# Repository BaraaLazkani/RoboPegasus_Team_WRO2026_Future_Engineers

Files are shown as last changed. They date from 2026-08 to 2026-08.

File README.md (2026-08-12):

RoboPegasus — WRO Future Engineers 2026
====

<p align="center">
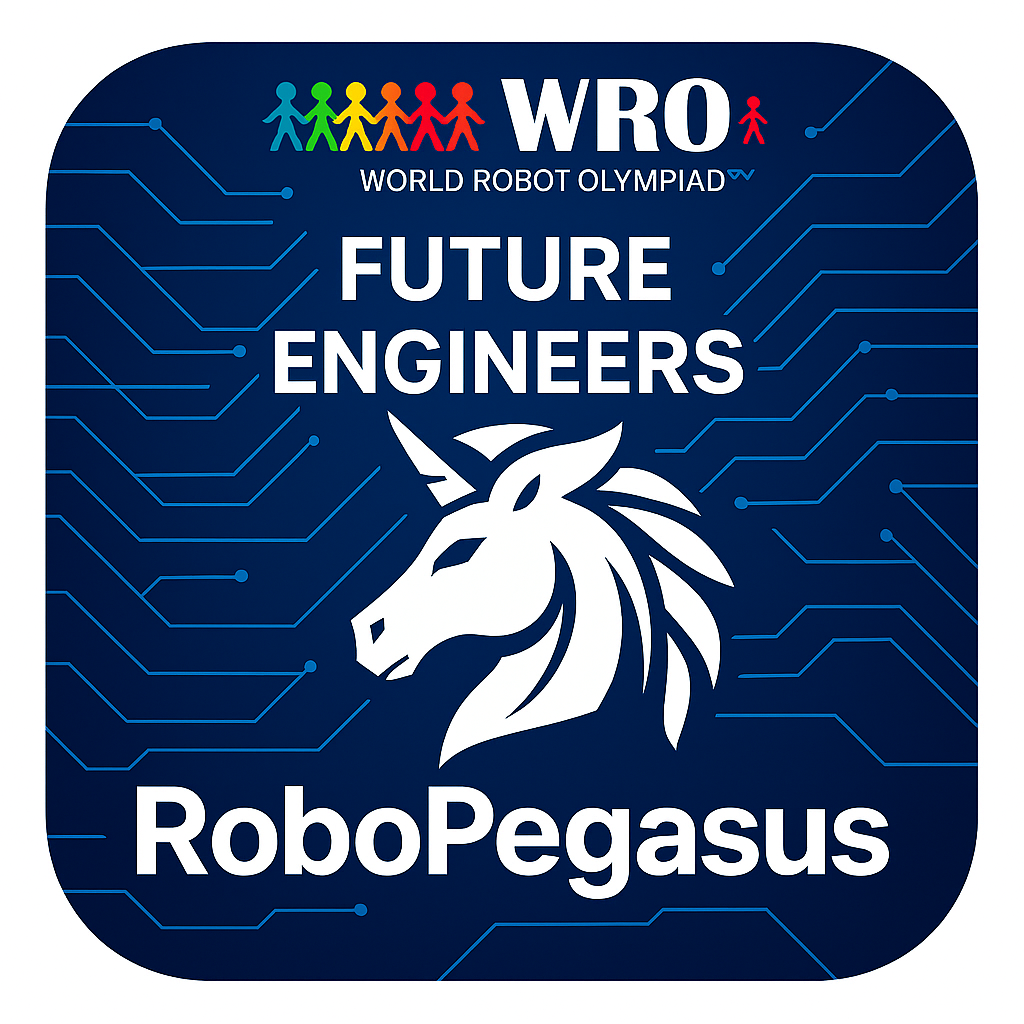
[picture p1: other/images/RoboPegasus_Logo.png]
RoboPegasus Logo
  
</p>

This repository holds the engineering documentation for RoboPegasus's
autonomous vehicle, built for the 2026 season of the WRO Future Engineers
competition.

### Table of contents

1. [Engineer's Documentation on GitHub](#engineers-documentation-on-github)
2. [Mobility and Mechanical Design](#mobility-and-mechanical-design)
3. [Power and Sensor Architecture](#power-and-sensor-architecture)
4. [Software Architecture and Obstacle Strategy](#software-architecture-and-obstacle-strategy)
5. [Systems Thinking and Engineering Decisions](#systems-thinking-and-engineering-decisions)
6. [Team and Age Groups Definitions](#team-and-age-groups-definitions)
7. [Responsibilities and Team's Own Work](#responsibilities-and-teams-own-work)
8. [Vehicle Material & Regulations Compliance](#vehicle-material--regulations-compliance)

## Engineer's Documentation on GitHub

### Repository

Our 2026 repository is public at
[github.com/BaraaLazkani/RoboPegasus_Team_WRO2026_Future_Engineers](https://github.com/BaraaLazkani/RoboPegasus_Team_WRO2026_Future_Engineers).
It will remain public for at least 12 months following the international
competition.

Access note: viewers in some restricted regions may need a VPN to reach
the repository.

### Repository structure

Our repository uses the following top-level folder structure:

```
.github/     # GitHub issue templates
t-photos/    # Team photos
v-photos/    # Vehicle photos (all sides, top, bottom)
video/       # Video demonstrations and links
schemes/     # Electrical schematics and diagrams
src/         # Source code for all components
models/      # 3D printed and laser cut parts
other/       # Additional resources (images, files, GIFs)
README.md    # This documentation
LICENSE      # Project license
CONTRIBUTING.md      # How to contribute
CODE_OF_CONDUCT.md   # Community code of conduct
SECURITY.md          # Security policy
```

`src/` contains every component we programmed for the competition.
`models/` contains the 3D-printed part files (`models/STL Files/`) and
laser-cut part files (`models/Cut/`) we used to fabricate the vehicle's
elements.

### Videos

Open Challenge: [youtube.com/watch?v=jy_cDW6b-VM](https://www.youtube.com/watch?v=jy_cDW6b-VM).

Obstacle Challenge: [youtube.com/watch?v=_Zi2wvzxyvg](https://www.youtube.com/watch?v=_Zi2wvzxyvg).

### Build, compile, and upload

The vehicle's control software splits into two parts, one for each of the
processors described in Power and Sensor Architecture:

- **Arduino Mega code** (sensor acquisition, motor control, real-time
  navigation): open the sketch in the Arduino IDE, select the Arduino
  Mega 2560 board and the correct serial port, then upload over USB.
- **Raspberry Pi code** (computer vision, pillar detection): run the
  Python script directly on the Pi with Python 3; no separate build step
  is required.

Once both boards are running, the Arduino and the Pi talk to each other
over a USB serial connection (see Power and Sensor Architecture:
Processing); source files for both live in `src/`.

### Vehicle photos

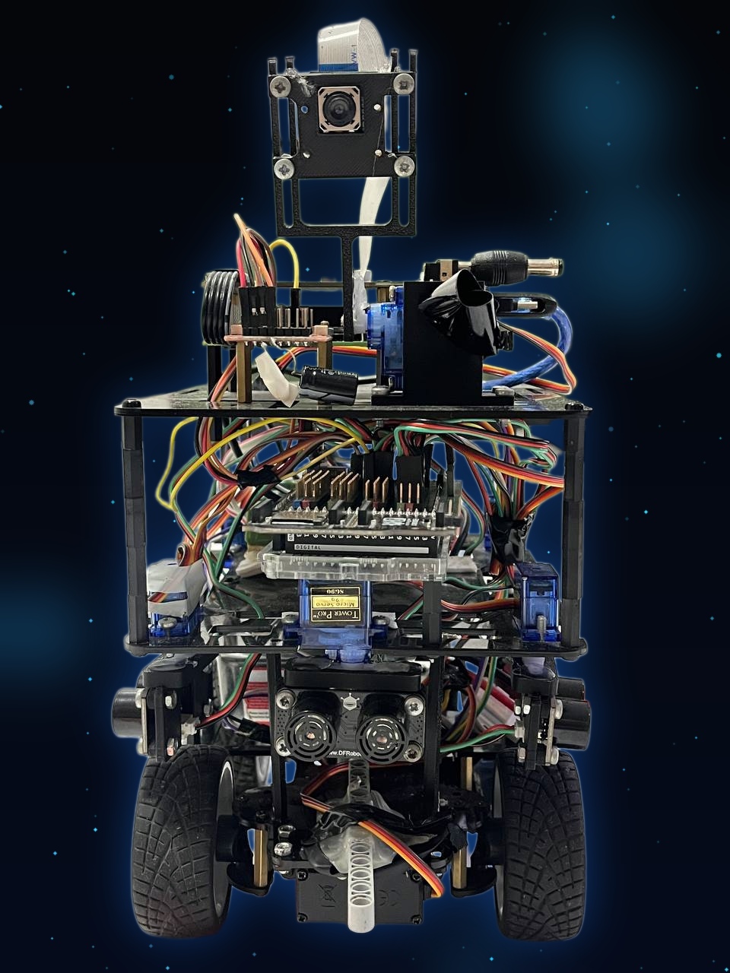
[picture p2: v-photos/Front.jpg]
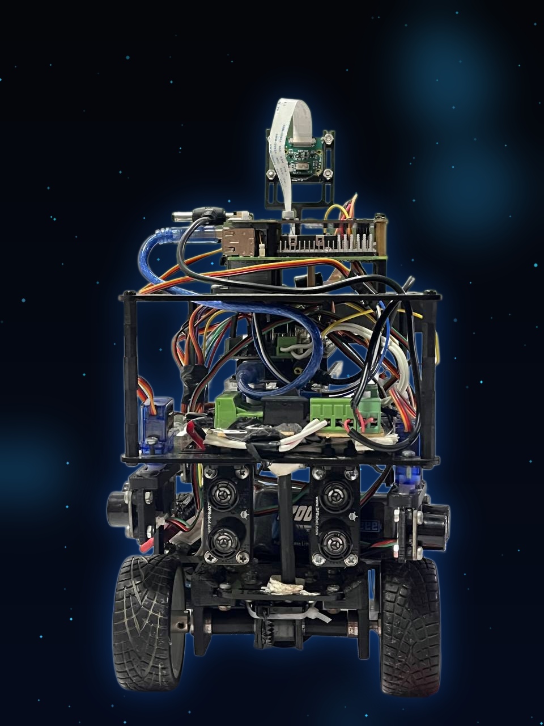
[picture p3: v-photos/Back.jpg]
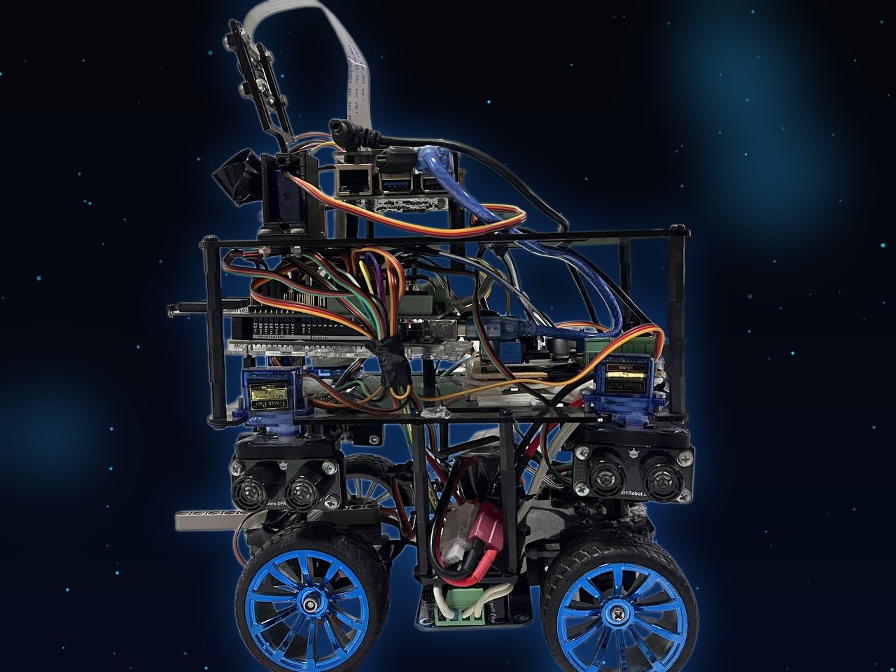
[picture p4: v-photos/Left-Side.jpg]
|  |  |  |
|:---:|:---:|:---:|
| _Front_ | _Back_ | _Left_ |
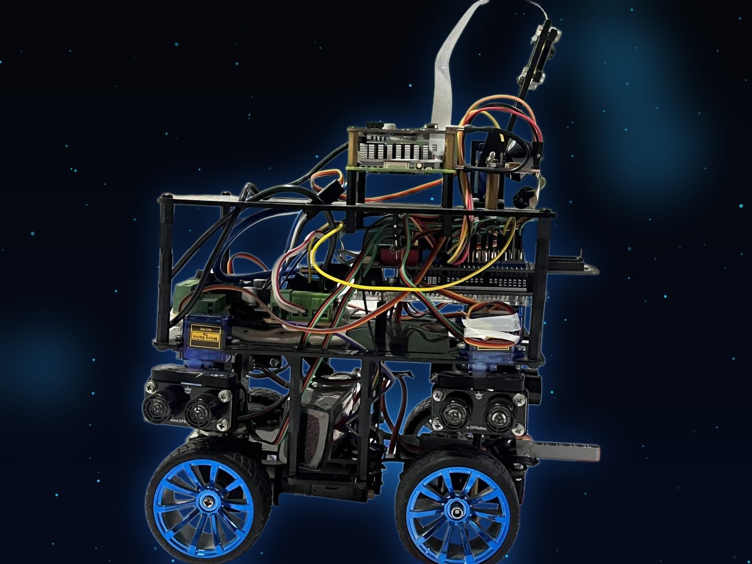
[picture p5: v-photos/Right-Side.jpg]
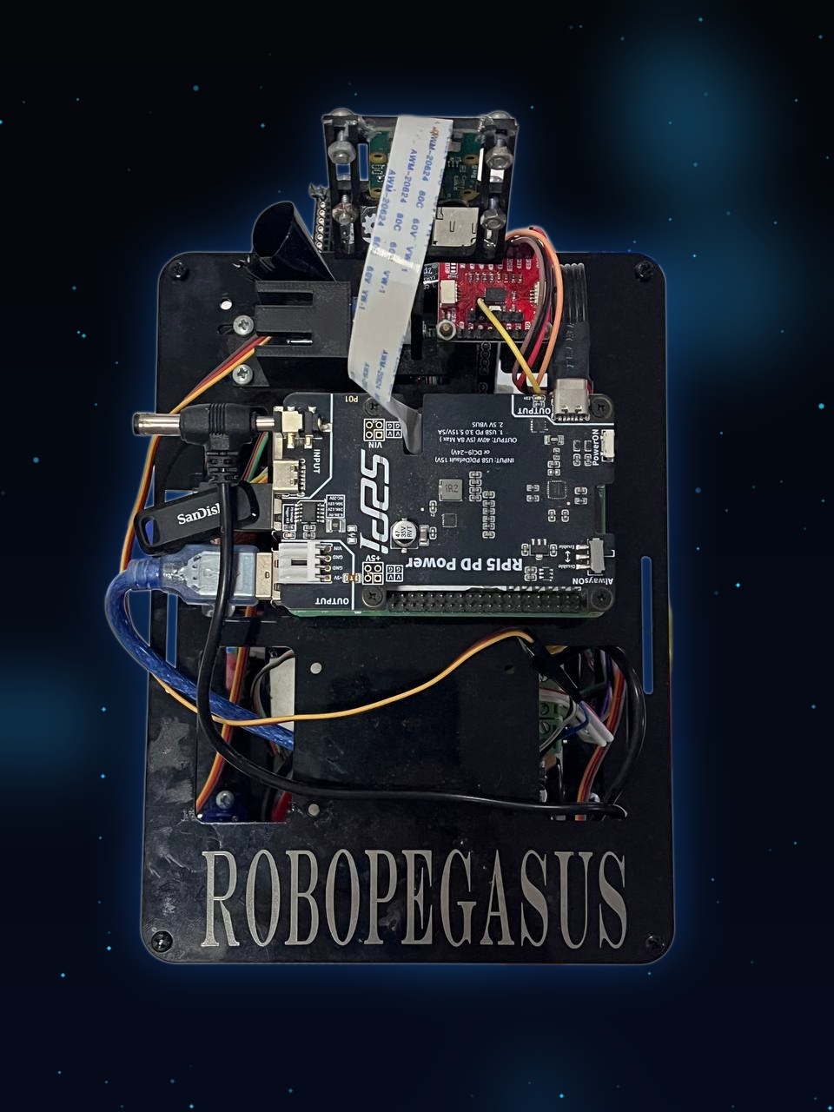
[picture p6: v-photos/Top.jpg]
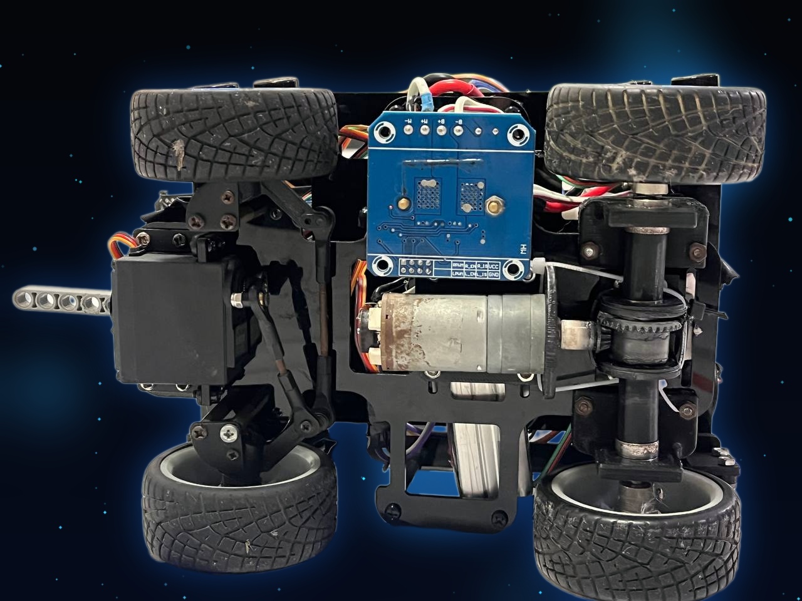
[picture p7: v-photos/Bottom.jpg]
|  |  |  |
| _Right_ | _Top_ | _Bottom_ |

Full-resolution versions of these photos live in `v-photos/`.

### Commit history

Commits go up continuously as work wraps, with every team member
contributing roughly evenly over time.

### Hard copy

This repository also includes a hard copy of this documentation, the
Engineering Journal (`Engineering-Journal.pdf`).

## Mobility and Mechanical Design

This section describes our chassis design choices, the steering and
drive mechanism, our torque/speed reasoning, and how we approached
mechanical stability and rigidity.

### Chassis

The chassis uses a hybrid material approach: 3mm plexiglass panels for
primary structural elements, combined with PLA 3D-printed components for
complex mechanical interfaces. Overall vehicle dimensions are 24cm length
x 15cm width x 29cm height, with a total system weight of 1.45kg.

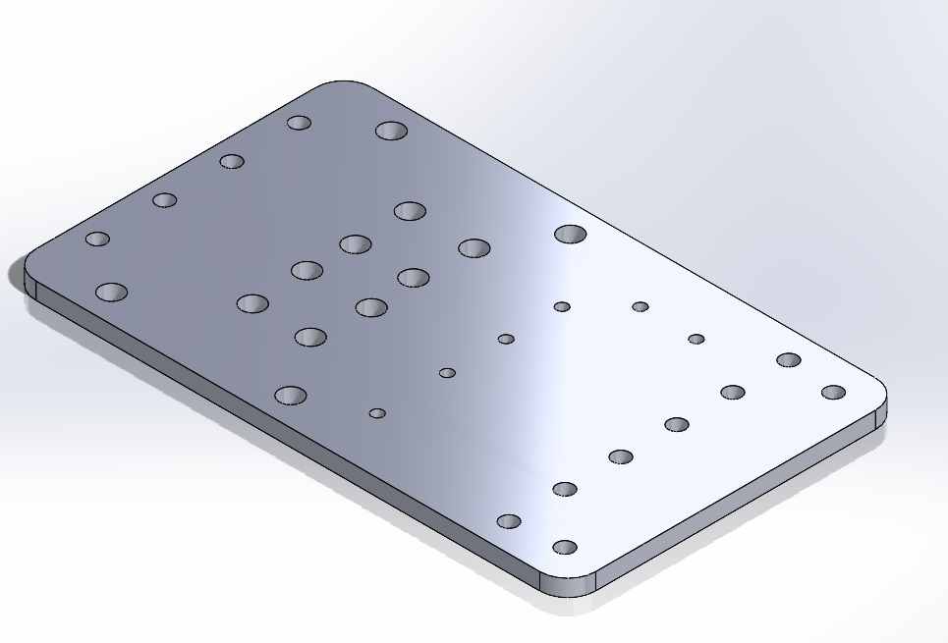
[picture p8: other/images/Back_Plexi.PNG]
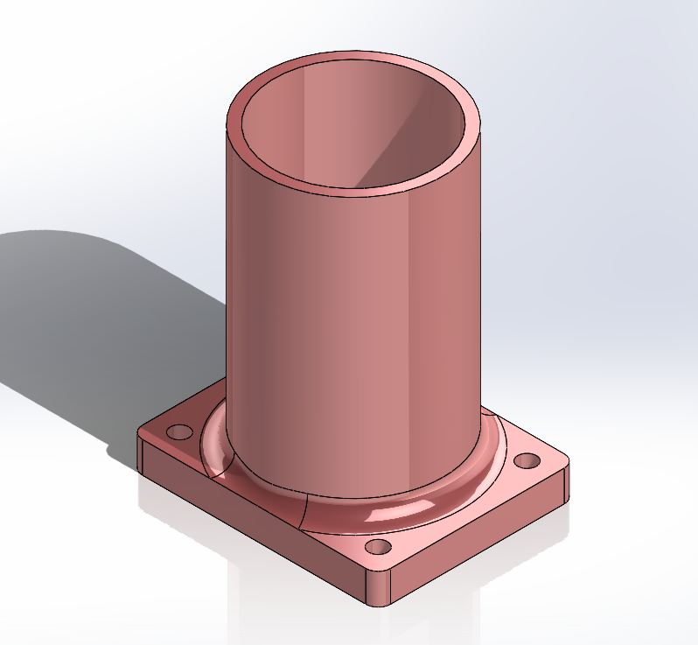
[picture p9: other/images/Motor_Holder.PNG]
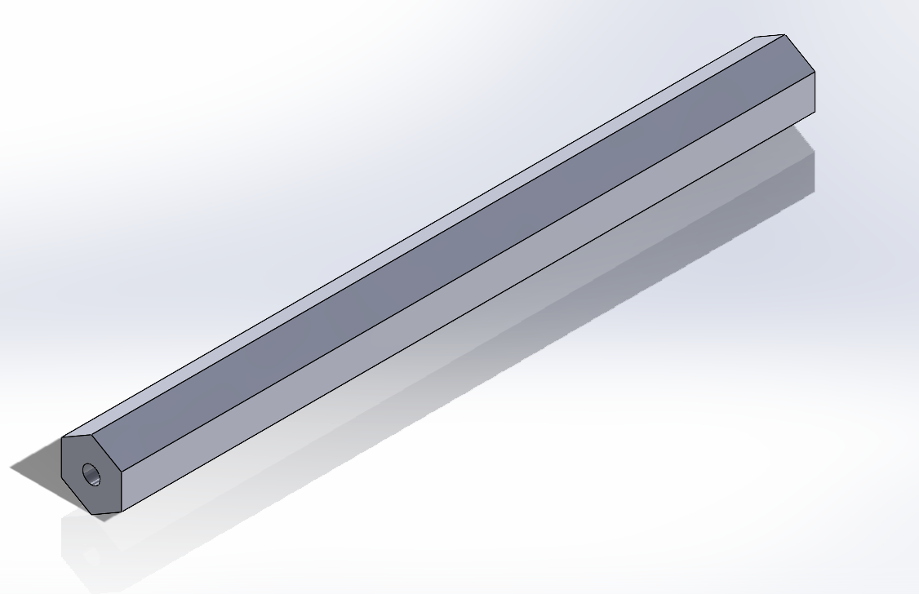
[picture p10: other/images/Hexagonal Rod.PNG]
|  |  |  |
|:---:|:---:|:---:|
| _Rear plexi panel with differential mechanism_ | _Motor holder_ | _Hexagonal drive rod_ |

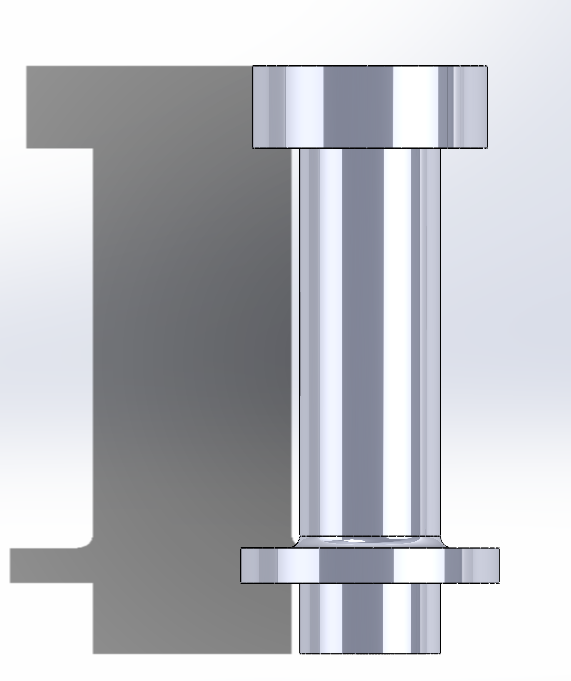
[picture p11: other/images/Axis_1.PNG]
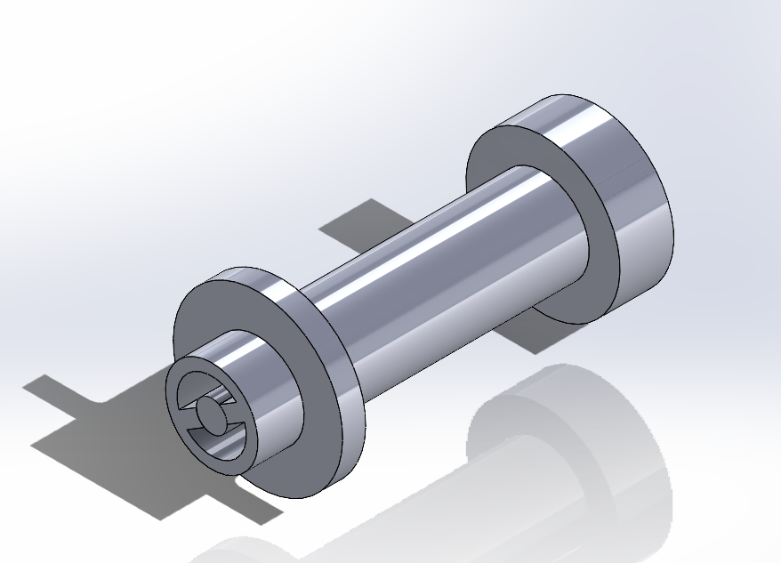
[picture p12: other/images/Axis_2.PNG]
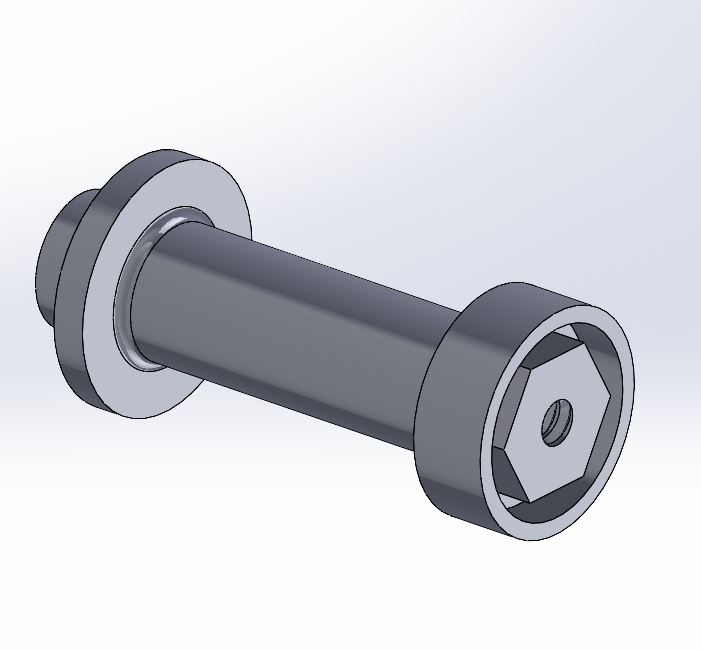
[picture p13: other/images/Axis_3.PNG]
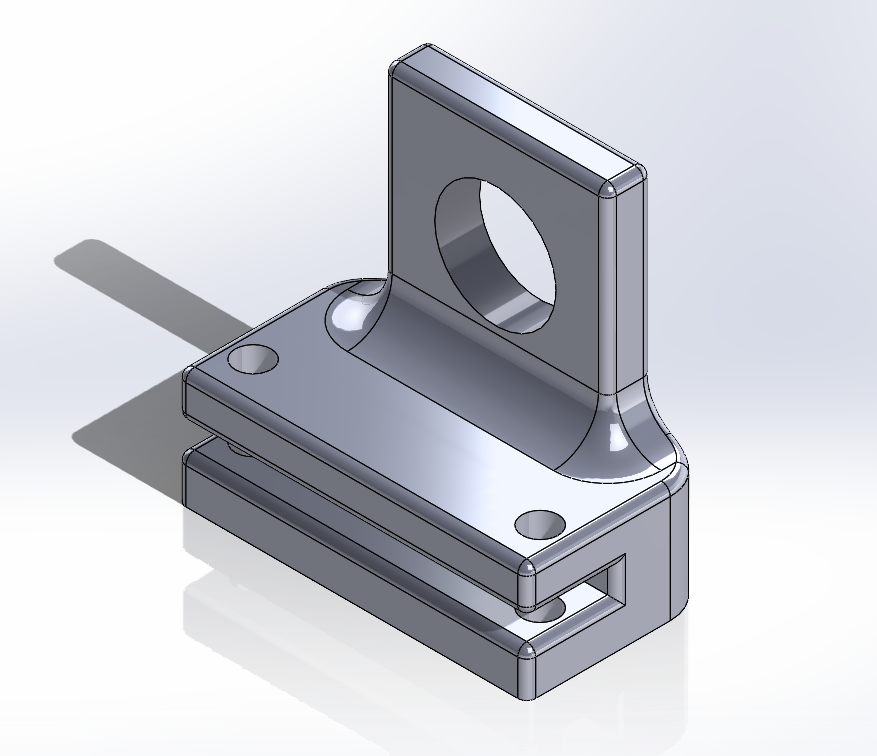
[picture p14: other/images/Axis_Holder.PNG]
|  |  |  |  |
|:---:|:---:|:---:|:---:|
| _Axis assembly, view 1_ | _Axis assembly, view 2_ | _Axis assembly, view 3_ | _Axis holder_ |

### Drivetrain

The primary drivetrain uses a JGA25-370 DC motor operating at 245 RPM,
selected for its balance of torque, power efficiency, and cost. At 12V, the
motor delivers 350 RPM no-load speed at 0.1A, reaching maximum efficiency
at 245 RPM with 1.4 kg-cm torque and 2.4W power consumption; its stall
specifications are 5.2 kg-cm torque at 2.2A. An integrated 3:1 gearbox
raises output torque to 4.2 kg-cm while reducing output speed to
approximately 82 RPM. With a 32mm wheel radius, this yields a tractive
force of approximately 12.85 N and a linear velocity of approximately
0.27 m/s at maximum efficiency, comfortably powering the 1,475g vehicle
(at an estimated 0.02 rolling-resistance coefficient, the calculated power
required for constant velocity is roughly 0.09W with the motor's ~90%
efficiency factored in) -- substantial reserve capacity above and beyond
the minimum required for propulsion, which we rely on for acceleration and
dynamic maneuvering.

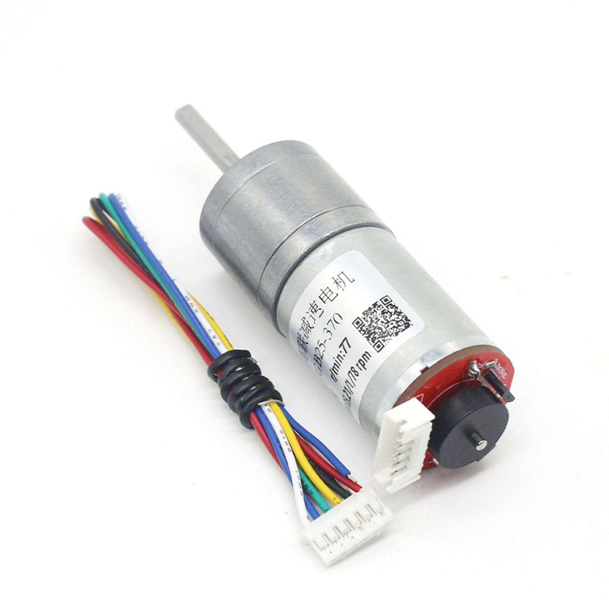
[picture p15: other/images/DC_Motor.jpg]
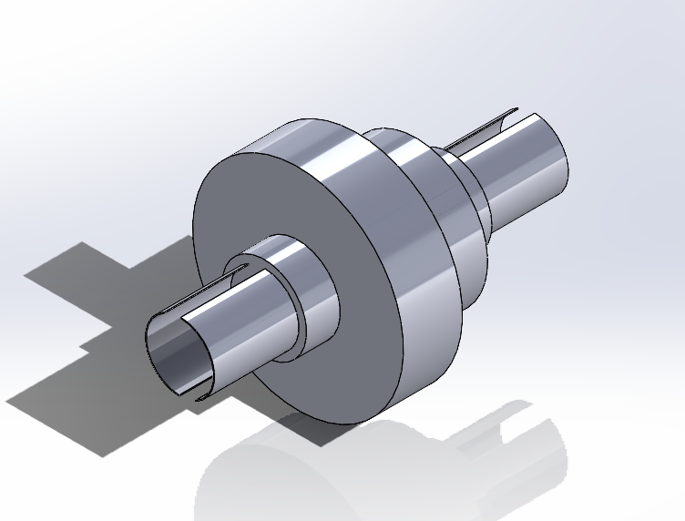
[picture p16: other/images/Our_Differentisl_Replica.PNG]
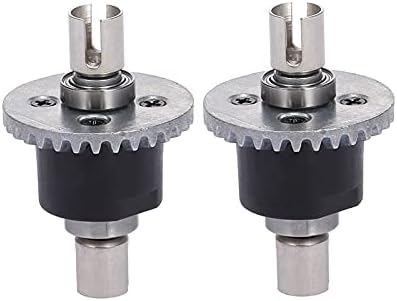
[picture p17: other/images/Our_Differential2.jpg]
|  |  |  |
|:---:|:---:|:---:|
| _JGA25-370 DC motor_ | _Custom differential replica_ | _Custom differential, view 2_ |
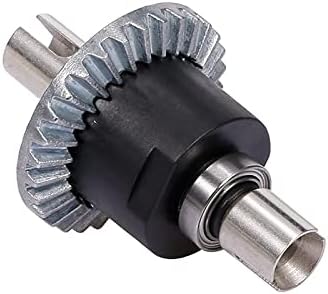
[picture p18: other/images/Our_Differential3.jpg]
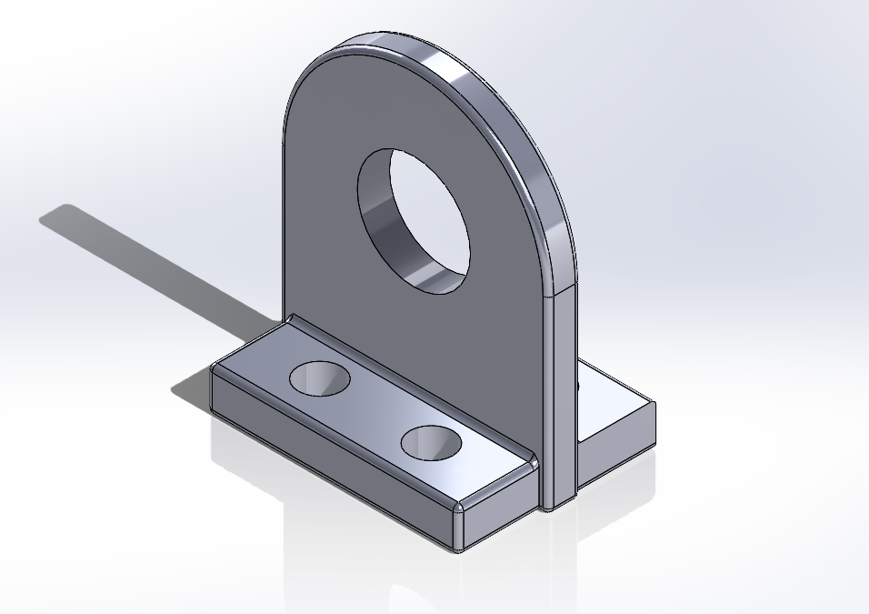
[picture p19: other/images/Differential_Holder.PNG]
|  |  | |
| _Custom differential, view 3_ | _Differential holder_ | |

Our rear axle uses a custom differential mechanism (not an electronic,
one-motor-per-side setup) -- for reference, the two broad differential
types this design draws on:

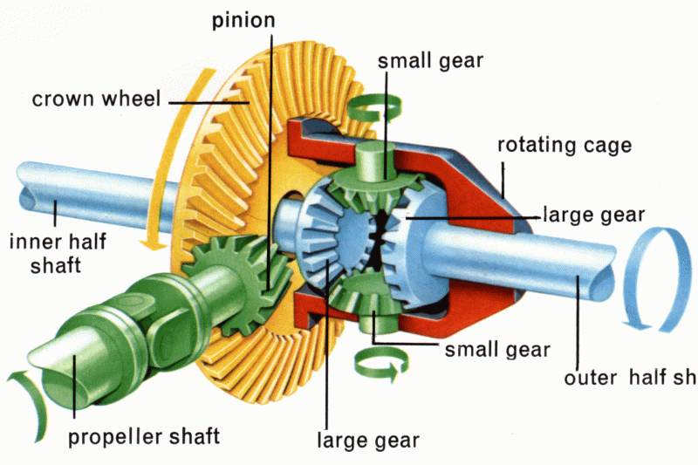
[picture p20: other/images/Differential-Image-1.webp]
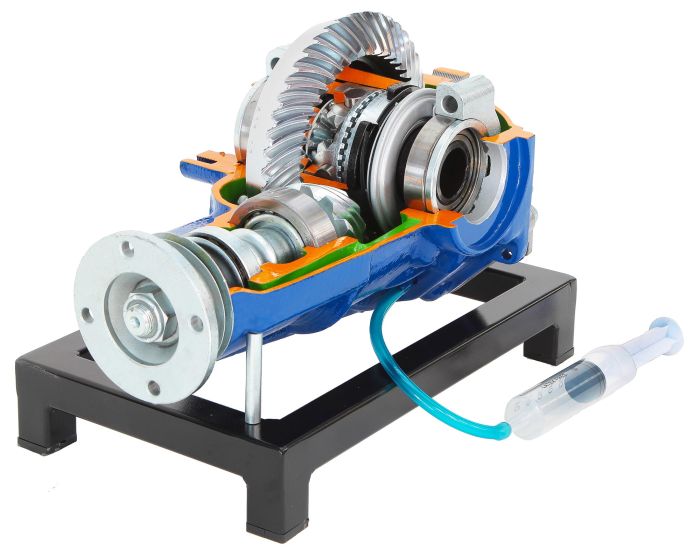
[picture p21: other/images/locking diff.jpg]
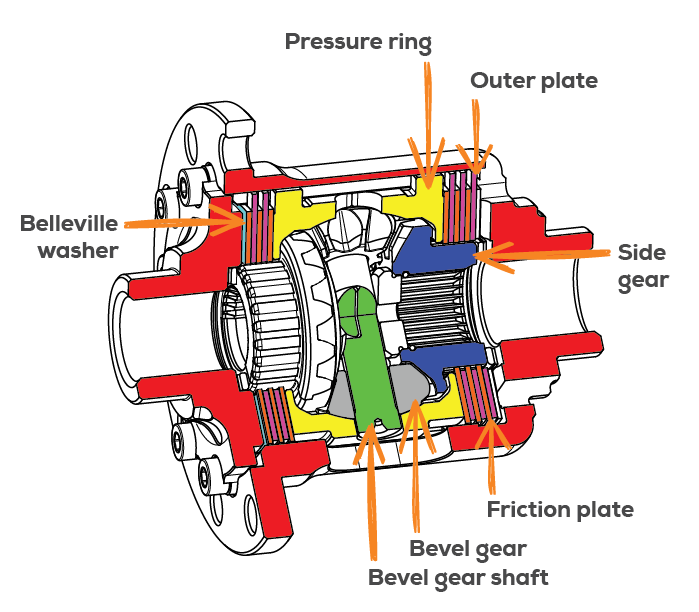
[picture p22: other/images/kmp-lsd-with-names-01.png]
|  |  |  |
|:---:|:---:|:---:|
| _Open differential_ | _Locking differential_ | _Limited-slip differential_ |

### Steering

The vehicle uses Ackermann steering, driven by an MG996R high-torque servo
(9.4 kg-cm stall torque at 4.8V, 11 kg-cm at 6V; 0.17s/60 degrees and
0.14s/60 degrees at those respective voltages), which receives direct PWM
signals from the Arduino Mega with no additional driver circuitry, keeping
steering-response latency low. The Ackermann steering geometry itself was
adapted from an existing 4WD Ackermann chassis kit -- the only major
component adapted from an outside design rather than built from scratch --
because the original kit's chassis platform (approximately 24cm) was far
larger than our target robot size (16-18cm). We identified the essential
mounting holes, pivot points, and structural elements from the forward
section of the original mounting plate, then used CAD modeling to
reproduce that section's exact hole spacing and angular relationships at
our compact scale, preserving the steering geometry while eliminating the
unusable length of the original plate.

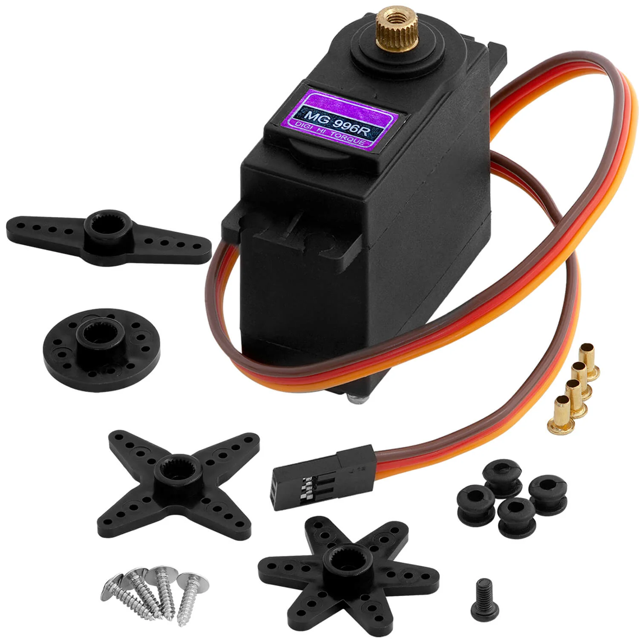
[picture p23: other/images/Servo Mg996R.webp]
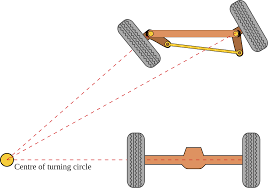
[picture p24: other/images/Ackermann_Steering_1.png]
|  |  |
|:---:|:---:|
| _MG996R steering servo_ | _Ackermann steering geometry_ |
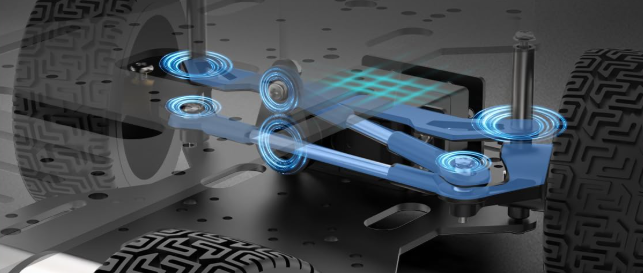
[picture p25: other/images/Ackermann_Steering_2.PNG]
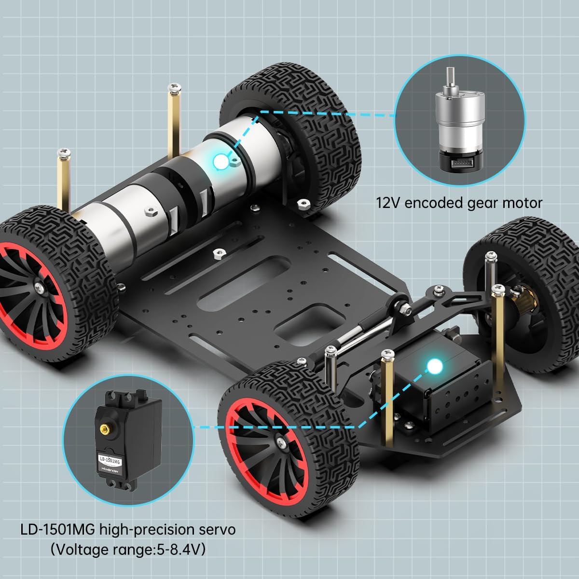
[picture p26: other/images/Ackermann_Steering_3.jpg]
|  |  |
| _Ackermann steering, how it works_ | _Original vs. custom design comparison_ |

### Testing and iteration

Before locking in the design, we validated our gear reduction and
drivetrain setup against our target performance figures.

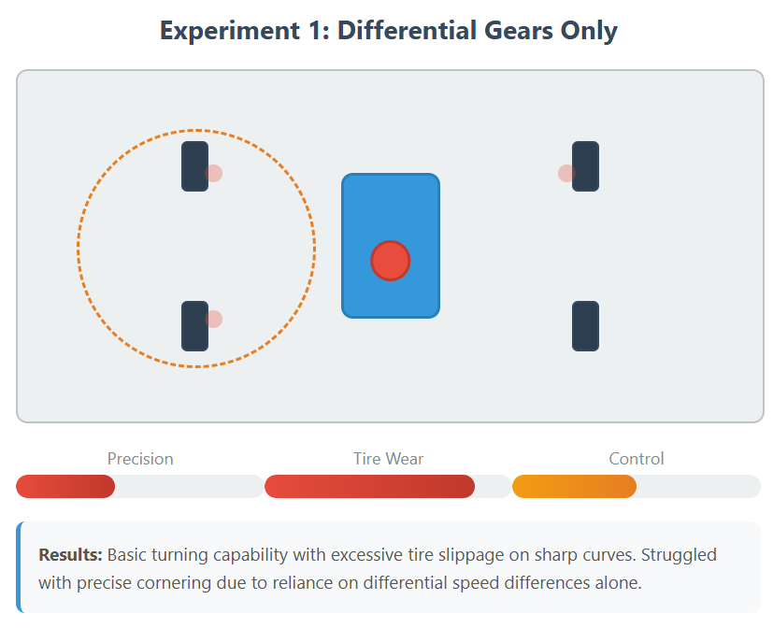
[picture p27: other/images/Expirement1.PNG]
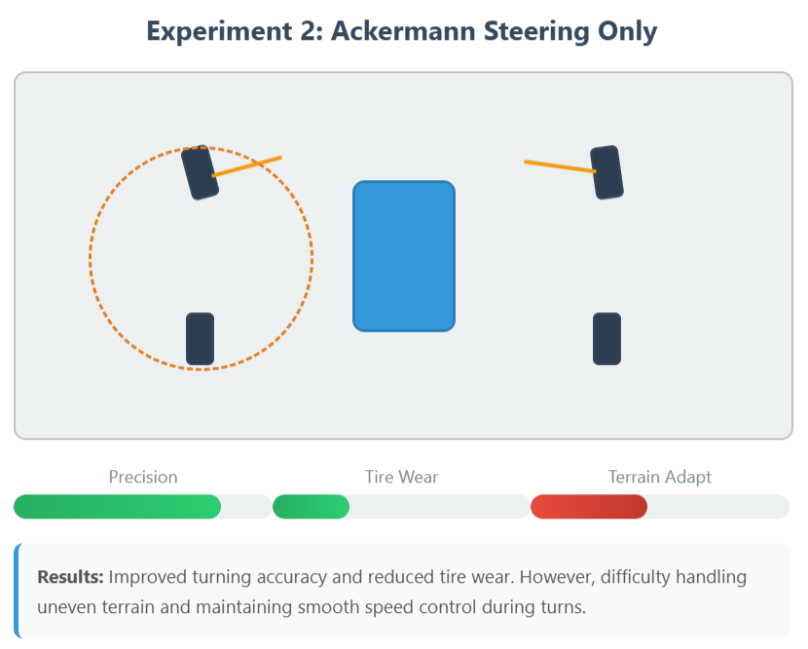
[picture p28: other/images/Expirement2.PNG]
|  |  |
|:---:|:---:|
| _Mechanical test 1_ | _Mechanical test 2_ |
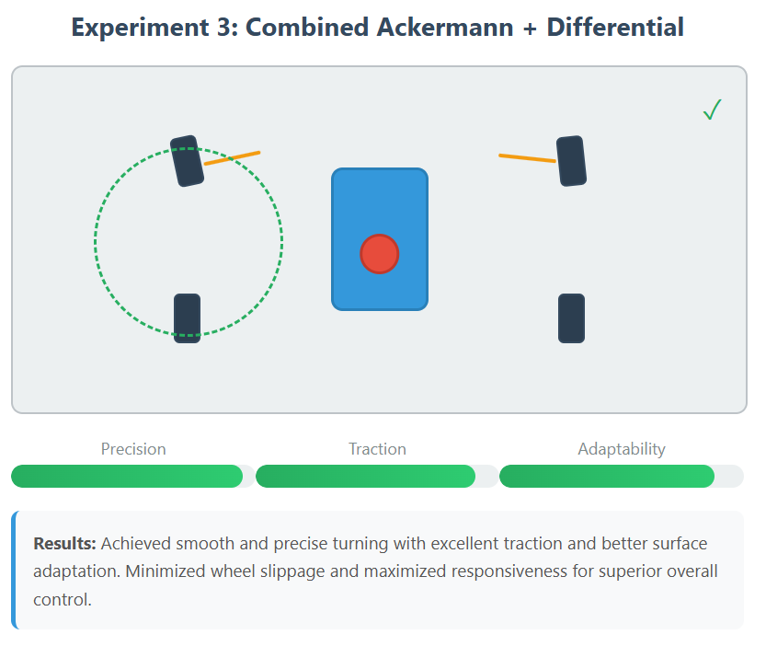
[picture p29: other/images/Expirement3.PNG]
|  |  |
| _Mechanical test 3_ | _Test legend_ |

The photos above show the gear-ratio testing described earlier.

Aside from the gear-ratio tuning covered above, we haven't yet written up
any further 2026-specific mechanical tests or design changes; that will
be added as the testing happens.

## Power and Sensor Architecture

This section walks through our power system architecture, the reasoning
behind our current draw and distribution, how sensors were chosen and
placed, our calibration approach, and the wiring diagrams.

### Power source and distribution

The robot is powered by a Zeee Li-Poly battery: 11.1V (3S configuration),
2200mAh capacity, 50C continuous discharge rate, up to 110A continuous
maximum current output, approximately 185g, with an XT60 connector. Power
is distributed using a custom Power Management System (PMS) built on a
star topology -- each component receives power directly from a central
distribution point rather than a daisy chain, which avoids voltage drops
and current-induced interference between subsystems, isolates each
component's current draw from the others, and simplifies fault isolation
and cable management. The battery's 50C/110A capacity comfortably covers
simultaneous peak demand from the drivetrain, processors, and sensor array
without voltage sag. At a typical estimated operating power draw, the
battery supports roughly 50 minutes of runtime, with a safety-factor
budget (80% battery usage) of roughly 41 minutes -- comfortably covering
multiple competition runs per charge.

The PMS includes a dedicated DC-DC step-down converter, which regulates
and stabilizes the battery's raw voltage down to what the Raspberry Pi 5
(SBC) and Arduino Mega (SBM) require.

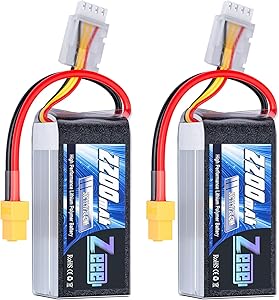
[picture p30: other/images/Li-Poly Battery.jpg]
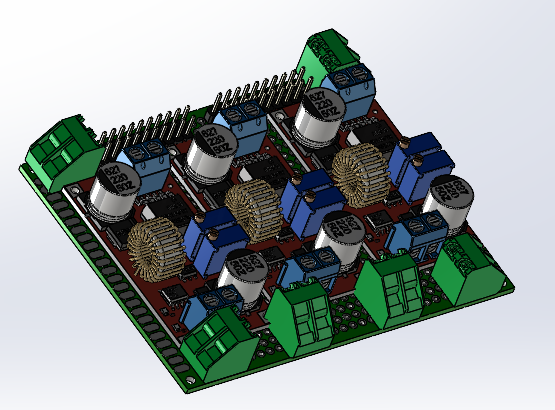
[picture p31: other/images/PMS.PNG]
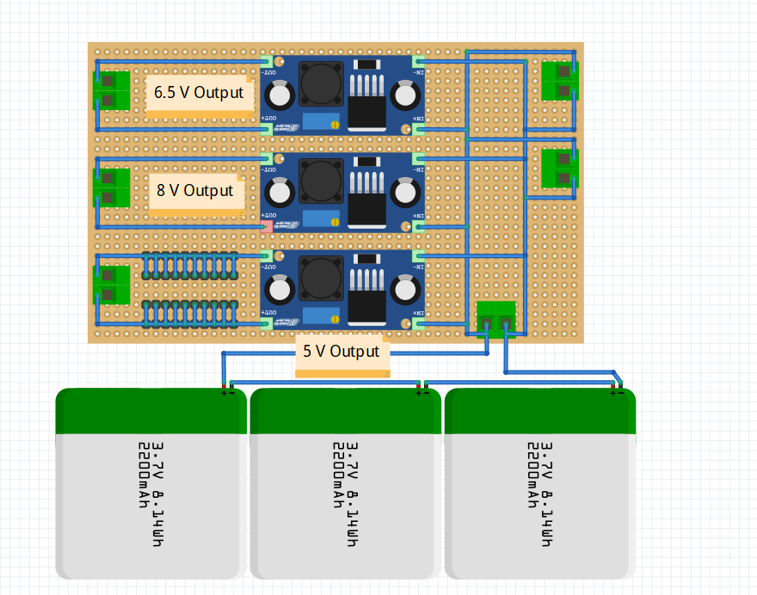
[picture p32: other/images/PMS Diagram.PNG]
|  |  |  |
|:---:|:---:|:---:|
| _Zeee Li-Poly battery, 11.1V 2200mAh_ | _Custom Power Management System_ | _PMS schematic diagram_ |

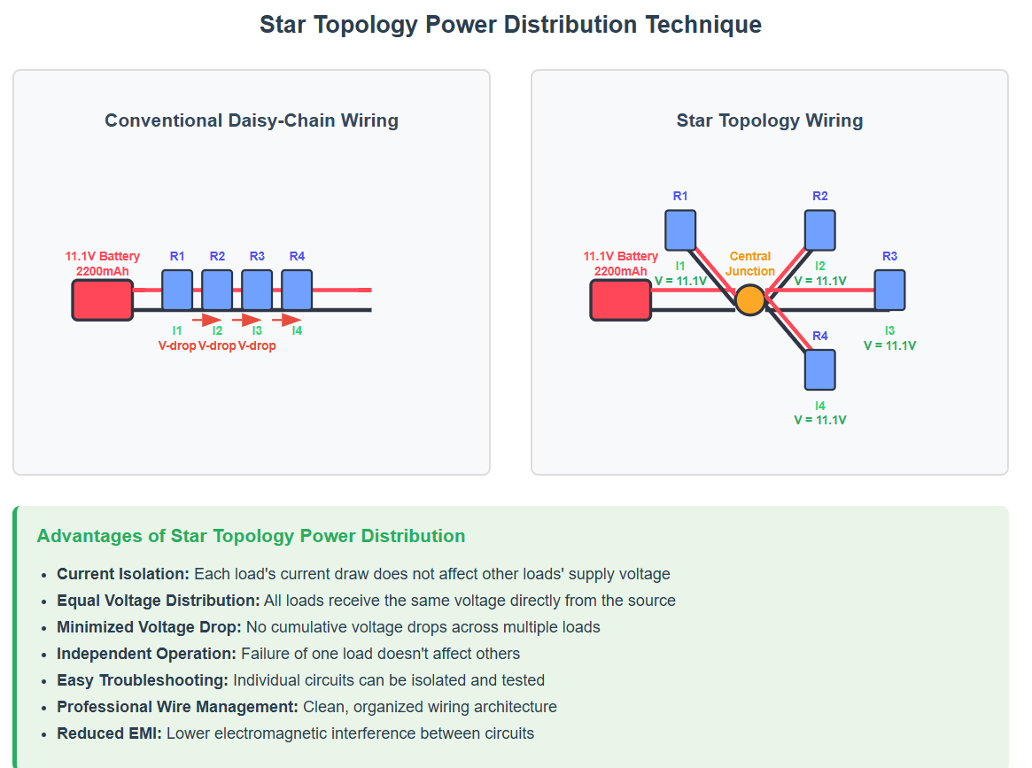
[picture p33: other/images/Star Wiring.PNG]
|  |
|:---:|
| _Star-topology power distribution_ |

### Processing

An Arduino Mega 2560 serves as the primary sensor interface and real-time
control processor -- handling sensor data acquisition, motor control, and
real-time navigation decisions -- chosen for its cost-effectiveness, 54
digital pins and 16 analog inputs (enough I/O for our full sensor array),
and proven reliability in robotics applications. A Raspberry Pi 5 (8GB RAM,
with active cooling) handles computer vision processing separately; active
cooling specifically guards against thermal throttling in high ambient
temperatures such as summer competition conditions. The two processors
communicate over a USB serial connection, exchanging computer vision
results and navigation commands.

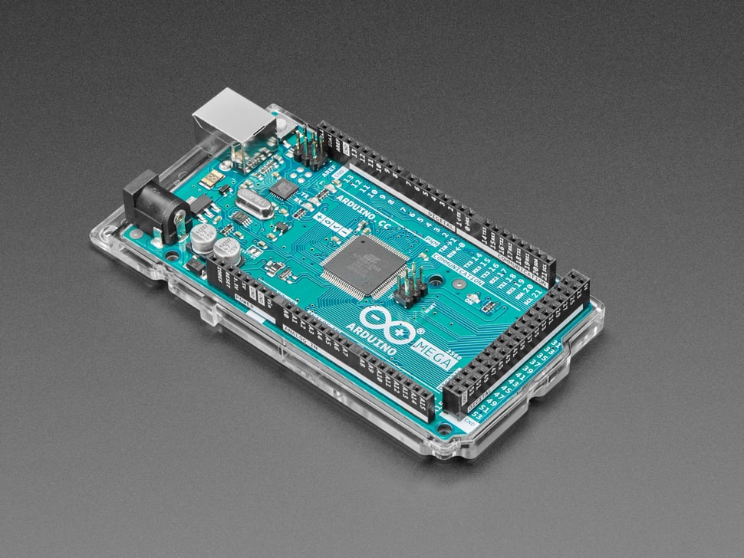
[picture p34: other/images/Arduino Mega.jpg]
|  |  |  |
|:---:|:---:|:---:|
| _Arduino Mega 2560_ | _Raspberry Pi 5 with active cooling_ | _BTS7960 motor driver_ |

### Sensor array

The sensor array is made up of 7 ultrasonic sensors, an IMU, and a camera:

- **Ultrasonic sensors:** 7x DFRobot URM09 (previously HC-SR04). Mounted
  below the 9cm height threshold for reliable wall detection.
- **Dynamic positioning:** 5 servos total (previously 3) -- both
  ultrasonic sensors on the left side now have servos, both on the right
  side now have servos, and the front ultrasonic sensor now also has a
  servo. Dynamic positioning keeps these sensors oriented perpendicular to
  walls regardless of vehicle attitude, which meaningfully improves
  measurement accuracy over a fixed angle.
- **IMU:** SparkFun BNO086 (previously MPU6050), providing orientation and
  acceleration data for dead reckoning and complementing the ultrasonic
  array for navigation.
- **Camera:** Arducam 64MP Hawk-Eye module, for computer vision tasks
  including pillar detection/classification and path planning.

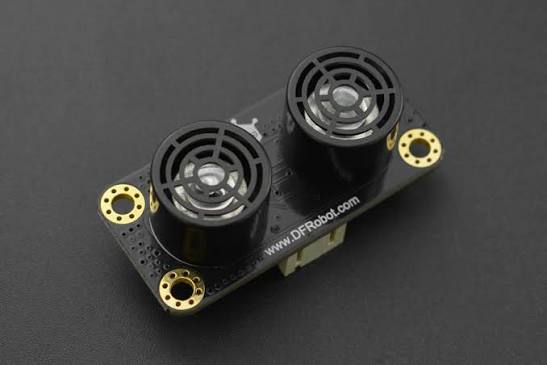
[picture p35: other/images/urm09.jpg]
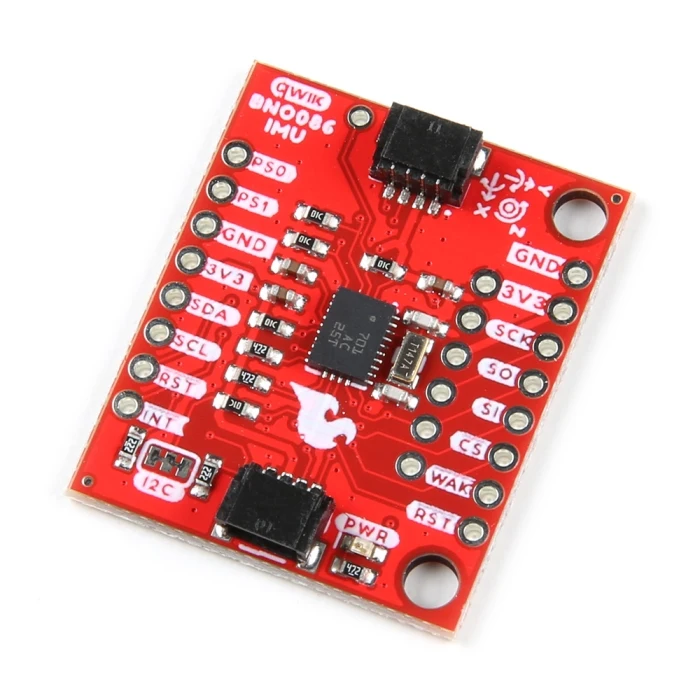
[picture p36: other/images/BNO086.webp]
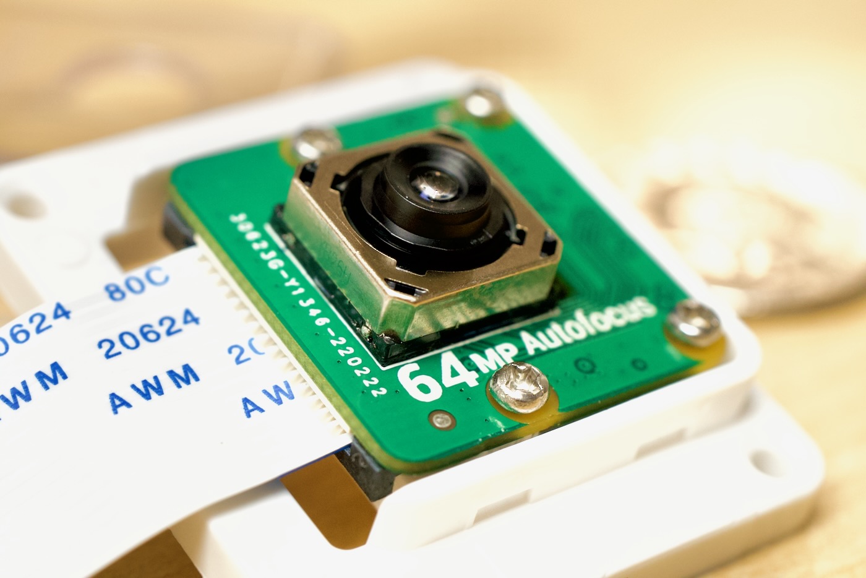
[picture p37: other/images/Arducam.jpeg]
|  |  |  |
|:---:|:---:|:---:|
| _DFRobot URM09 ultrasonic sensor_ | _SparkFun BNO086 IMU_ | _Arducam 64MP Hawk-Eye camera_ |

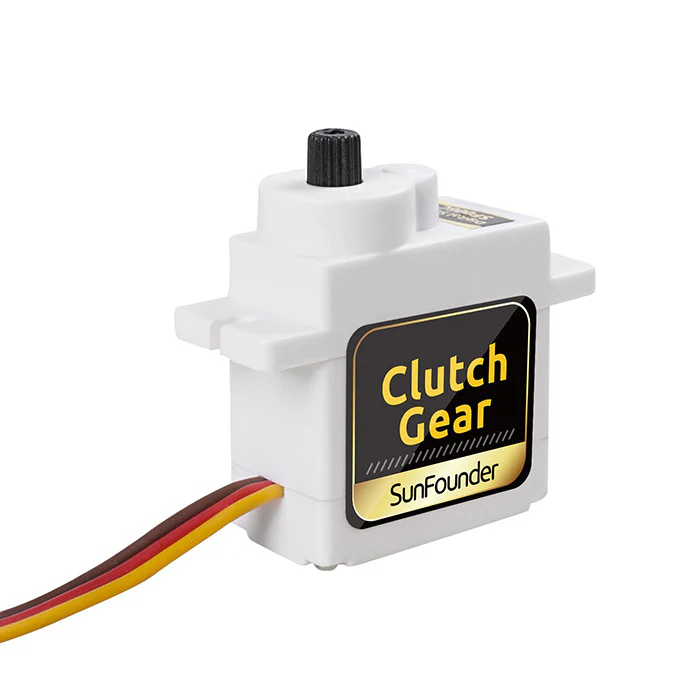
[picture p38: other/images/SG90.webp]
|  |
|:---:|
| _SG90 servo, dynamic sensor positioning_ |

### Sensor placement: field geometry and failure-point reasoning

We chose sensor placement based on how the robot's own geometry shifts
relative to the walls during a maneuver, not on a generic "more sensors
is better" logic:

- **Two rear ultrasonics** let the parking routine know when the robot is
  fully inside the parking lot -- a distinct requirement from the side
  sensors' wall-following role.
- **Two ultrasonics per side (front-axle and rear-axle),** rather than
  one, because which end of the robot is actually closest to the wall
  depends on the maneuver: driving forward while turning right brings the
  *front* of the robot closest to the wall, while driving backward while
  turning right brings the *back* of the robot closest to the wall. A
  single side sensor would be reading the wrong distance during roughly
  half of these maneuvers; having one sensor near each axle means the
  relevant distance is always available on both sides regardless of
  direction of travel or turn.
- **The same front/rear-axle side-sensor pair also compensates for IMU
  drift:** since the two sensors' physical separation is known, the robot
  can geometrically compute how many degrees it has actually drifted from
  the two distance readings, and use that to correct the MPU/IMU heading
  reference over time -- a concrete failure-point mitigation for sensor
  drift, not just a navigation feature.
- **The front ultrasonic** exists specifically to detect obstacles
  directly ahead of the robot, a role none of the side/rear sensors can
  fill.
- **Servos on the ultrasonics** exist because ultrasonic ranging accuracy
  degrades sharply once the reflecting surface isn't perpendicular to the
  sensor -- dynamic positioning keeps each sensor perpendicular to the
  wall regardless of the robot's current attitude, which is the whole
  reason the sensor count and servo count both grew for 2026 (see above).

### Bill of materials

A consolidated list of the vehicle's major components, pulled together
from the descriptions above and in Mobility and Mechanical Design:

| Component | Part | Qty | Price (USD) |
|---|---|---|---|
| Chassis | 3mm plexiglass panels + PLA 3D-printed parts | -- | -- |
| Drive motor | JGA25-370 DC motor, 3:1 gearbox | 1 | $20 |
| Steering servo | MG996R high-torque servo | 1 | $8 |
| Sensor-positioning servos | SG90 | 5 | $5 ($1 each) |
| Motor driver | BTS7960 | 1 | $4 |
| Primary controller (SBM) | Arduino Mega 2560 | 1 | $50 |
| Vision processor (SBC) | Raspberry Pi 5, 8GB RAM, active cooling | 1 | $120 |
| Ultrasonic sensors | DFRobot URM09 | 7 | $70 ($10 each) |
| IMU | SparkFun BNO086 | 1 | $34 |
| Camera | Arducam 64MP Hawk-Eye | 1 | $80 |
| Battery | Zeee Li-Poly, 11.1V (3S), 2200mAh, 50C, XT60 | 2 | $80 |
| Power distribution | Custom PMS, star topology, DC-DC step-down converter | 1 | $20 |
| **Total** | | | **$491** (excludes chassis material cost) |

### Wiring diagram

The wiring diagram
(`schemes/Full Schematic Circuit Diagram of the Robot/Full Circuit Diagram
of the Robot.PNG`) was produced in Fritzing, which does not have exact
component symbols for the URM09 ultrasonic or BNO086 IMU, so those two
components are represented with generic/illustrative symbols rather than
exact part renders -- the diagram is accurate for overall wiring topology,
not a literal part-for-part illustration of the newest sensors.

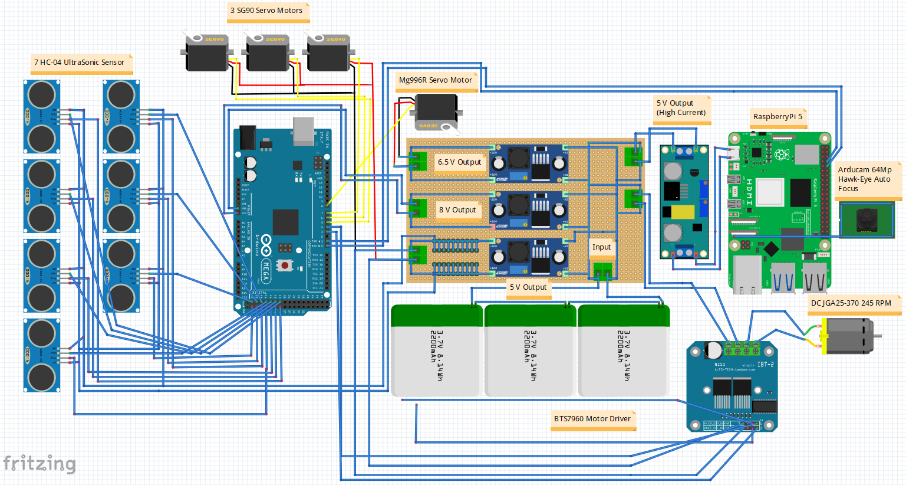
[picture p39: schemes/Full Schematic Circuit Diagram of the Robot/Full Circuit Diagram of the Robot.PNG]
Full Schematic Circuit Diagram of the Robot


### Calibration

Neither the DFRobot URM09 ultrasonic sensors nor the SparkFun BNO086 IMU
required a dedicated calibration procedure -- both performed reliably
right out of the box, so no team-developed calibration methodology exists
for either.
The camera's color thresholds (used for pillar detection, see Software
Architecture and Obstacle Strategy) are tuned through a dedicated
calibration routine. That routine is intentionally not published in this
repository, to avoid exposing our original color-detection work to being
copied by other teams.

## Software Architecture and Obstacle Strategy

This section explains our code structure and control flow, along with the
lane-following and obstacle-avoidance strategy and algorithms behind it.

### Open Challenge navigation

At startup, the robot reads distance from its left and right ultrasonic
sensors (`d_left`, `d_right`) to establish its spatial relationship to the
surrounding walls, and determines its driving direction by comparing them:
CCW if the right distance is less than the left, CW otherwise. During a
lap, the robot executes a turning maneuver whenever either ultrasonic
sensor detects an opening (a distance reading greater than 120cm),
adapting its turning logic to the section geometry it detects, and
continues wall-following/turning until the required number of laps is
complete.

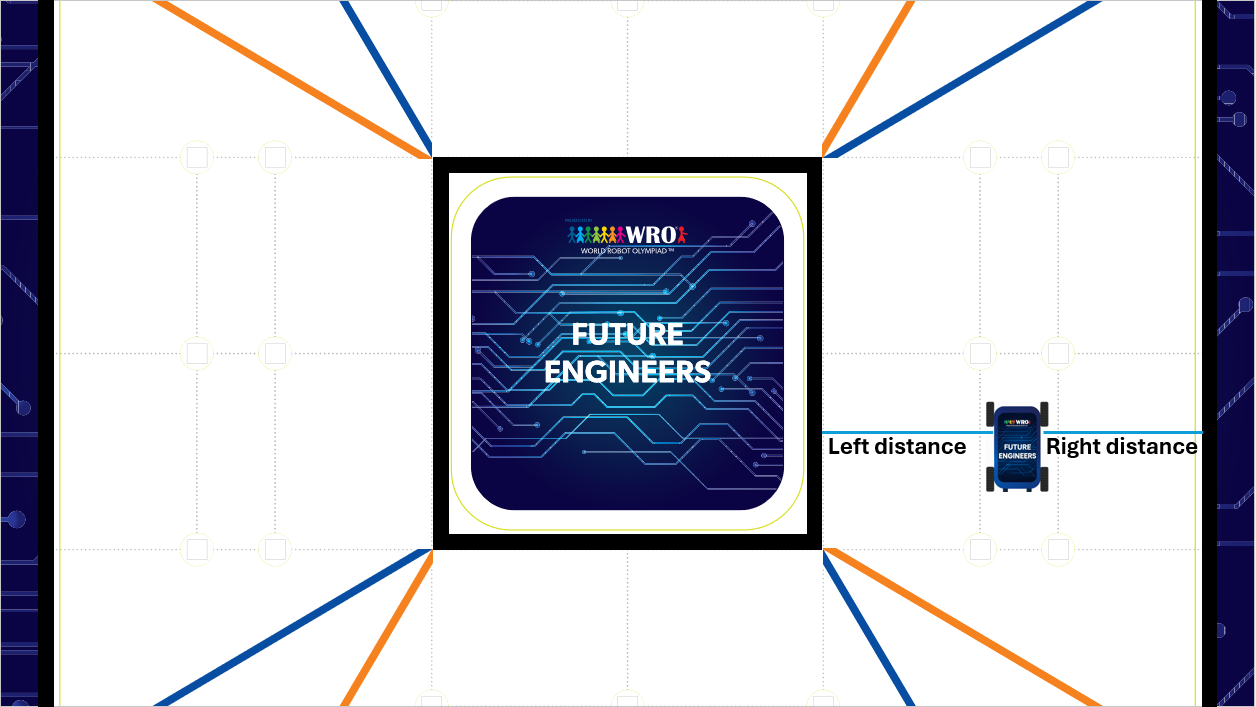
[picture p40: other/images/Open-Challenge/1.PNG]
|  |  |
|:---:|:---:|
| _Initial position assessment_ | _Right wall avoidance, step 1_ |
|  |  |
| _Right wall avoidance, step 2_ | _Reference tracking control_ |
|  |  |
| _Turn initiation condition_ | _Turn execution_ |

|  |  |
|:---:|:---:|
| _Algorithm flowchart, part 1_ | _Algorithm flowchart, part 2_ |

|  |
|:---:|
| _Algorithm flowchart, combined_ |

|  |
|:---:|
| _Open Challenge demonstration_ |

### Obstacle Challenge: pillar detection

Pillar color is detected and classified via the Raspberry Pi 5's computer
vision pipeline, distinguishing red and green pillar configurations
(Red-Green, Green-Red, Red-Red, and Green-Green cases) to determine which
side of the lane to keep. Detected color masks feed directly into the
navigation logic to decide the lane-keeping side for each pillar
encountered.

|  |  |  |  |
|:---:|:---:|:---:|:---:|
| _Red-Green, camera view_ | _Red-Green, color mask_ | _Green-Red, camera view_ | _Green-Red, color mask_ |
|  |  |  |  |
| _Red-Red, camera view_ | _Red-Red, color mask_ | _Green-Green, camera view_ | _Green-Green, color mask_ |

Examples of single-pillar detection (used by the color duplication
algorithm when only one pillar color appears in frame):

|  |  |  |  |
|:---:|:---:|:---:|:---:|
| _Single red pillar, camera view_ | _Single red pillar, color mask_ | _Single green pillar, camera view_ | _Single green pillar, color mask_ |

### State machine and control flow

The obstacle-challenge control flow is organized as a state machine built
around per-pillar handling functions. The diagram and the function names
below describe the algorithm's structure and ideas, not a literal
function-by-function map of the code in `src/` -- see `src/` for the
actual function names.

```mermaid
flowchart TD
    Start(["Start"]) --> Startup["Startup: exit parking (CW/CCW)"]
    Startup --> FirstPillar["First pillar: photo + pass_first_pillar()"]
    FirstPillar --> Reposition["Reposition + photo"]
    Reposition --> LapCheck{"Lap 1 complete?"}
    LapCheck -- "No: next pillar" --> PhotoPass["Photo + pass pillar"]
    PhotoPass --> LapCheck
    LapCheck -- "Yes" --> LapsCheck{"3 laps complete?"}
    LapsCheck -- "No: next pillar" --> DirectPass["Pass pillar directly, no photo"]
    DirectPass --> LapsCheck
    LapsCheck -- "Yes" --> Parking["Backward parking"]
    Parking --> End(["End"])
```

1. **Startup.** The robot exits the parking section; the startup sequence
   itself differs depending on whether the run is CW or CCW.
2. **First pillar.** The robot takes a photo and calls a `pass_first_pillar`
   function, selected by the detected color and by CW/CCW direction.
3. **Repositioning.** After `pass_first_pillar` completes, a maneuver
   (dependent on the robot's current position) repositions the robot ready
   for the next section and the next photo.
4. **Subsequent pillars.** Each pillar is handled by a function named for
   its color combination and direction (for example `Red_Red_ccw`,
   `Red_Green_ccw`). There are also `<Color>_None_<direction>` variants
   (for example `Red_None_ccw`) that currently behave identically to their
   same-color counterpart; these exist specifically to have a defined
   behavior ready in case a pillar's expected color signal changes under
   the season's Surprise Rule, which can add or modify existing rules
   before the international final.
5. **After the first lap,** the robot already knows each pillar's color
   from the first pass, so it stops taking photos and passes each pillar
   directly using the already-determined color/direction function.
6. **Shared control primitives**, used inside every pillar-passing
   function:
   - `turn_right` / `turn_left` -- discrete turning maneuvers.
   - `dual_pid` -- follows both an MPU/IMU heading reference and a target
     distance from a specific wall simultaneously.
   - `MPU_PID` -- follows only an MPU/IMU heading reference, with no wall
     distance term.
7. **Parking.** The robot always parks from the same fixed
   position/orientation regardless of which direction the lap ran in, so
   a `reverse_cw_to_ccw` function (or its opposite) flips the approach
   direction where needed so the final parking maneuver is always
   consistent, using the Backward Parking method described below.

**Red pillar case:**

|  |  |
|:---:|:---:|
| _Step 1_ | _Step 2_ |
|  |  |
| _Step 3_ | _Step 4_ |
|  | |
| _Step 5_ | |

|  |
|:---:|
| _Startup, CCW, red pillar case_ |

**Green pillar case:**

|  |  |
|:---:|:---:|
| _Step 1_ | _Step 2_ |
|  |  |
| _Step 3_ | _Step 4_ |
|  |  |
| _Step 5_ | _Step 6_ |
|  | |
| _Step 7_ | |

|  |
|:---:|
| _Startup, CCW, green pillar case_ |

**Clockwise (CW) navigation mode:**

|  |  |
|:---:|:---:|
| _Step 1_ | _Step 2_ |
|  |  |
| _Step 3_ | _Step 4_ |

|  |
|:---:|
| _Startup, CW case_ |

**Example scenario -- post-CCW red pillar transition (corner positioning):**

|  |  |
|:---:|:---:|
| _Step 1_ | _Step 2_ |
|  | |
| _Step 3_ | |

|  |
|:---:|
| _Corner positioning protocol_ |

**Visual example -- Green-Red, counter-clockwise:**

|  |  |
|:---:|:---:|
| _Step 1_ | _Step 2_ |
|  |  |
| _Step 3_ | _Step 4_ |
|  |  |
| _Step 5_ | _Step 6_ |
|  |  |
| _Step 7_ | _Step 8_ |

|  |
|:---:|
| _Green-Red, CCW case_ |

### Parking

The robot walks past the parking lot first, then enters it in reverse
from the rear axle, rather than entering forward from the front as in
previous seasons. We call this the Backward Parking method:

1. **Approach detection.** The robot drives backward along the lane, using
   its rear-right sensor to monitor for the parking entrance. When the
   entrance gap is detected, it continues a small additional distance to
   confirm it has reached the correct spot (avoiding a false trigger at
   the wall edge).
2. **Maneuver.** The robot steers right and reverses into the parking lot
   entrance. As soon as the back half of the robot clears the first wall,
   it steers left to align itself parallel with the walls. This reversing
   trajectory is smoother and gives more precise alignment control than
   the forward-entry approach used previously.
3. **Sensing.** Parking uses a combination of sensors: ultrasonic sensors
   mounted on the sides and rear measure distance from the parking lot
   walls and detect the entrance gap; the IMU (now the SparkFun BNO086,
   see the Power and Sensor Architecture section) provides orientation and
   heading for precise turning.

#### Testing

The reworked backward-entry parking maneuver has been tested 100 times,
succeeding on all 100 attempts.

Together, the state machine above and the parking trial results (100/100
successful attempts) show structured testing and tuning of our
lane-following and obstacle-avoidance strategy; a per-lap intervention
count or PID tuning narrative for the open-challenge wall-following
controller specifically is still missing -- that gap remains to be
filled.

## Systems Thinking and Engineering Decisions

Rather than treating each subsystem in isolation, this section looks at
how they work together (mobility, power, sensors, software, frame), the
reasoning behind our engineering decisions, the constraints and tradeoffs
we navigated, our iteration and testing cycles, and how we identified and
mitigated risk.

### Constraints we designed within

**Vehicle envelope.** WRO caps overall vehicle dimensions at 300x200mm and
300mm in height, and caps weight at 1.5kg.
Our vehicle's 1,475g mass (see Mobility and Mechanical Design) sits
comfortably under that limit.

**Wheelbase and turning radius.** We studied the robot's overall length
and the wheelbase (front-to-rear axle distance) specifically to determine
the turning radius we needed. We empirically tested extending the robot's
length using an added rod, and found 4cm was the safe, best-performing
addition -- long enough to meaningfully help with parking maneuvering,
without pushing length past what the rest of the design could
accommodate.

**Width vs. turning radius tradeoff.** We wanted the robot as narrow as
possible (while staying long enough for the turning-radius requirement
above), but our Ackermann steering mechanism constrained how narrow we
could actually go: the robot's width ended up set by the front axle's
track width, since that's the span the Ackermann geometry needs to
function correctly. This is a direct example of "we chose X instead of Y
because..." reasoning -- we didn't choose the width freely; the steering
mechanism we'd already committed to (see Mobility and Mechanical Design)
determined it.

**Power switching.** Only one switch is allowed to power the vehicle on.
That single-switch constraint is a direct reason we engineered a custom
Power Management System (see Power and Sensor Architecture) rather than
wiring components independently: with only one legal point of entry for
power, a centralized, star-topology distribution design was the only way
to cleanly deliver power to every subsystem from that single switch.

**Processing/startup time.** The Raspberry Pi 5's boot process and Python
library loading originally took approximately 90 seconds combined -- time
that competes directly with the window judges allow the robot to become
ready before starting the competition countdown. To bring this down, we
switched to headless/lightweight versions of our libraries instead of
their full desktop-oriented builds, and disabled Pi system services we
didn't need at boot. This got the robot moving well within that startup
window.

### Iteration and testing

Apart from the specific 2026 changes already documented -- the DFRobot
URM09/SparkFun BNO086 sensor swap, the added servos, the 4cm
wheelbase-extension rod, the reworked backward-entry parking maneuver,
and the Pi startup-time optimization above -- this season is largely an
incremental refinement of last year's platform, not a ground-up redesign.

### Risk identification and mitigation

We identified and addressed two concrete failure modes at the system
level, rather than treating them as isolated sensor concerns:

- **IMU drift.** The MPU/IMU heading reference can drift over time. We
  mitigate this using the geometric relationship between each side's two
  ultrasonic sensors (front-axle and rear-axle) -- the robot calculates
  its actual drift angle from their two distance readings and corrects
  the heading reference accordingly (see Power and Sensor Architecture).
- **Ultrasonic accuracy loss off-perpendicular.** Ultrasonic ranging
  degrades sharply once the reflecting surface isn't perpendicular to the
  sensor. We mitigate this with servo-driven dynamic positioning, keeping
  every relevant ultrasonic sensor perpendicular to the wall regardless of
  the robot's current attitude (see Power and Sensor Architecture).

In both cases, a single-subsystem fix (better IMU calibration, a single
fixed sensor) wouldn't have been enough -- the real solution came from
the interaction between two subsystems (sensing geometry and control
software).

## Team and Age Groups Definitions

### Our team

RoboPegasus is made up of 3 students, guided by a single coach:

- **Coach:** Baraa Lazkani
- **Students:** Hasan Mfleh, Hadi Moalla, Haidar Saad

At 3 students and 1 coach, our team is comfortably above the minimum size
the rules exclude -- a lone team member paired with a single coach isn't
a valid team and can't participate.

### Category and team membership

This season the team competes only in the Future Engineers category,
in line with the rule limiting a team to one WRO category per season.
Hasan, Hadi, and Haidar each belong to this team exclusively, following
the rule that a student may only be on one team.

### Age eligibility

For 2026, this category's age group spans students aged 14-22, born
between 2004 and 2012.
Eligibility for this window is based on the age a participant turns
during the 2026 calendar year, not their age on competition day.
All three of our students fall within this window: Haidar Saad was born
in 2004 (turning 22 in 2026, the oldest age this category allows), and
Hasan Mfleh and Hadi Moalla were both born in 2005.

Our coach, Baraa Lazkani, was also born in 2004 -- turning 22 in 2026,
comfortably above the minimum coach age of 18 years old required at
international events.
A coach is allowed to work with more than one team.

## Responsibilities and Team's Own Work

Our team competes fairly and treats other teams, coaches, judges, and
organizers with respect. Taking part in WRO means we accept its Guiding
Principles, and every team member plus our coach have already signed the
WRO Ethics Code.

### Ownership of the work

All coding of the vehicle and its construction was done solely by the
team -- our coach's role has been to support us organizationally and with
questions or problems, not to program or build the vehicle themselves,
consistent with the rule that coaching may not include programming the
vehicle or its construction.
Our control program and design are our own work: the state machine,
navigation algorithms, and sensor integration described in the Software
Architecture and Power and Sensor Architecture sections were built by the
team, not copied from or too similar to a solution sold online or used by
another team.
The one exception is our Ackermann steering mechanism, which adapts the
geometry of an existing 4WD chassis kit, customized and re-integrated
into our own compact chassis design (see Mobility and Mechanical
Design).

### Competition-day conduct

During the competition, our team will not communicate in any way with
anyone outside the competition area, except where a judge specifically
permits supervised communication.
Team members will not bring or use mobile phones or any other
communication device in the competition area.
We won't damage or interfere with competition courts, tables, materials,
or other teams' vehicles.

### Consequences of violations

Should any of these rules be broken, judges may interview the team or
individual members about the vehicle or program before deciding what
consequences apply.
Suspected violations specifically related to independent construction
(rule 3.3) or original work (rule 3.7) can trigger an investigation, with
consequences up to preventing the team from progressing to the next
competition even if they would otherwise place well.

## Vehicle Material & Regulations Compliance

This section verifies our vehicle satisfies the rules' physical and
material requirements, referencing back to the measurements and
component choices already documented in Mobility and Mechanical Design
and Power and Sensor Architecture.

### Size and weight

At 29cm x 17.5cm x 29cm and 1,475g (see Mobility and Mechanical Design),
our vehicle sits comfortably within the rules' limits: dimensions capped
at 300x200mm and 300mm in height, weight capped at 1.5 kilograms.

### Drivetrain and wheels

Our vehicle is a 4-wheeled, rear-wheel-drive vehicle with Ackermann
steering at the front axle (see Mobility and Mechanical Design), which
satisfies the requirement that a vehicle be 4-wheeled with one driving
axle and one steering actuator, built as front-wheel, rear-wheel, or
four-wheel drive -- not a differential wheeled base.
Our wheels are plain rubber wheels, not omnidirectional wheels, ball
casters, or spherical wheels.
A single JGA25-370 motor drives the rear axle through a custom
differential mechanism and gearbox (see Mobility and Mechanical Design) --
well within the maximum of two driving motors allowed, connected directly
or through gearing rather than independently to each wheel, and not an
electronic differential with one motor per side.

### Autonomy and communication

The vehicle operates fully autonomously with no radio communication or
remote control while running (see the state machine described in
Software Architecture and Obstacle Strategy).
Consistent with this, no team member interferes with or assists the
vehicle once a round is running -- no manual data entry, visual, audio,
or other signaling to the vehicle during a run.
The Raspberry Pi 5's built-in WiFi and Bluetooth hardware is disabled
during competition runs, satisfying the requirement that any built-in
wireless capability be turned off and confirmable by judges.
Every connection between our electromechanical components -- sensors,
motors, and the two processors -- is a wired connection; no wireless
links exist anywhere in the sensor or communication chain, satisfying the
requirement that only wire connections be used for inter-component
communication.

### Controllers and materials

Our controllers -- a Raspberry Pi 5 (SBC) and an Arduino Mega 2560 (SBM)
(see Power and Sensor Architecture) -- satisfy the rule allowing either
controller type with no brand restriction.
Our chassis uses a plexiglass and PLA 3D-printed hybrid construction (see
Mobility and Mechanical Design), which the rules permit -- any material or
building system is allowed, with no restriction to a specific type.

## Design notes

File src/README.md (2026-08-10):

Control software
====

- `open_challenge/open_challenge.ino` -- Arduino Mega code for the Open Challenge.
- `obstacle_challenge/arduino_code/arduino_code.ino` -- Arduino Mega code for the Obstacle Challenge.
- `obstacle_challenge/python_code/Obsatcle-Challenge.py` -- Raspberry Pi computer-vision code for the Obstacle Challenge (pillar color detection).

See the main README's "Build, compile, and upload" section for how to run this code on the vehicle's controllers.

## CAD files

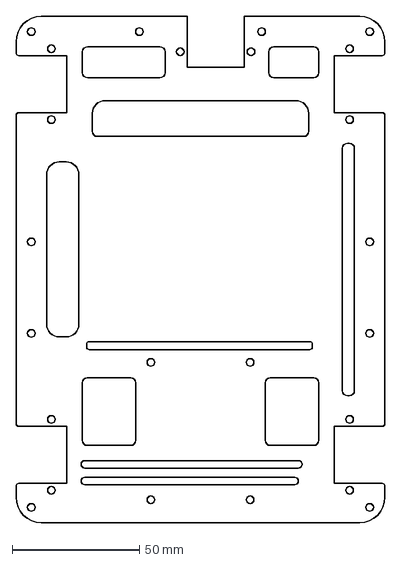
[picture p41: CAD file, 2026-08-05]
models/Cut/Second_Plexi.DXF
145.0 x 199.0 mm

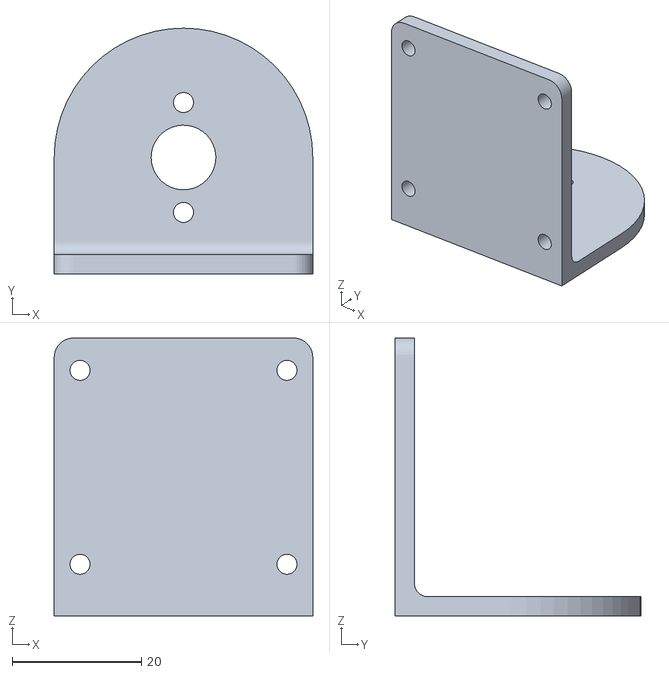
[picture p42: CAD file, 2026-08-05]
models/STL Files/finalMotor_Holder.STL
40.0 x 38.0 x 43.0

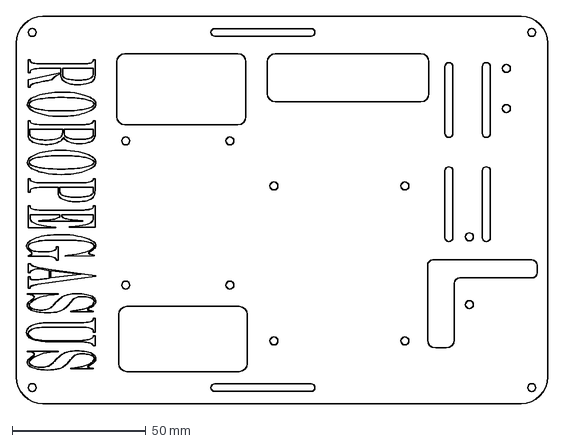
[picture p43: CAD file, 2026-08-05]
models/Cut/Roof_Plexi.DXF
199.0 x 145.0 mm

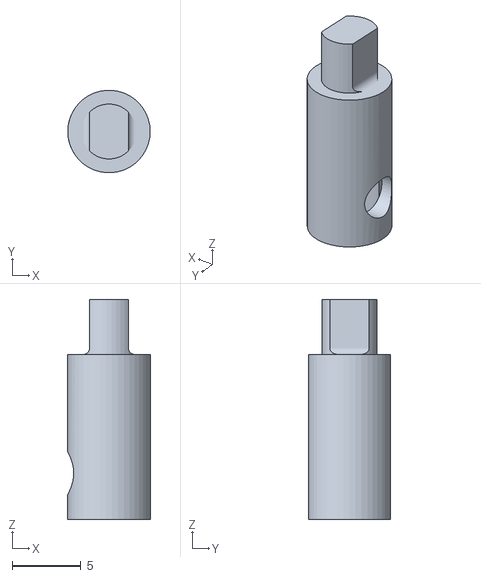
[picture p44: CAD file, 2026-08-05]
models/STL Files/finaldc_to_diff.STL
6.00 x 5.98 x 16.0

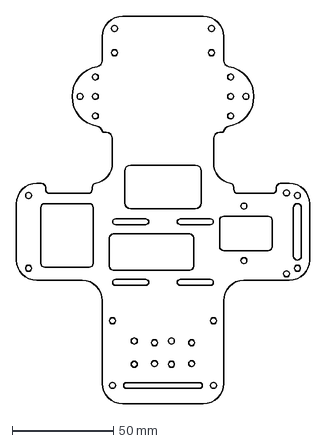
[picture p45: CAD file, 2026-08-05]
models/Cut/Floor_Plexi.DXF
145.0 x 191.6 mm

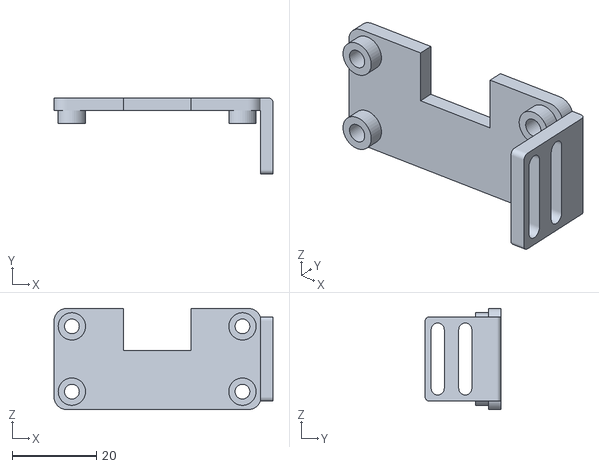
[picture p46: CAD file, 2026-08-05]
models/STL Files/finalultra_back.STL
52.0 x 18.0 x 24.0

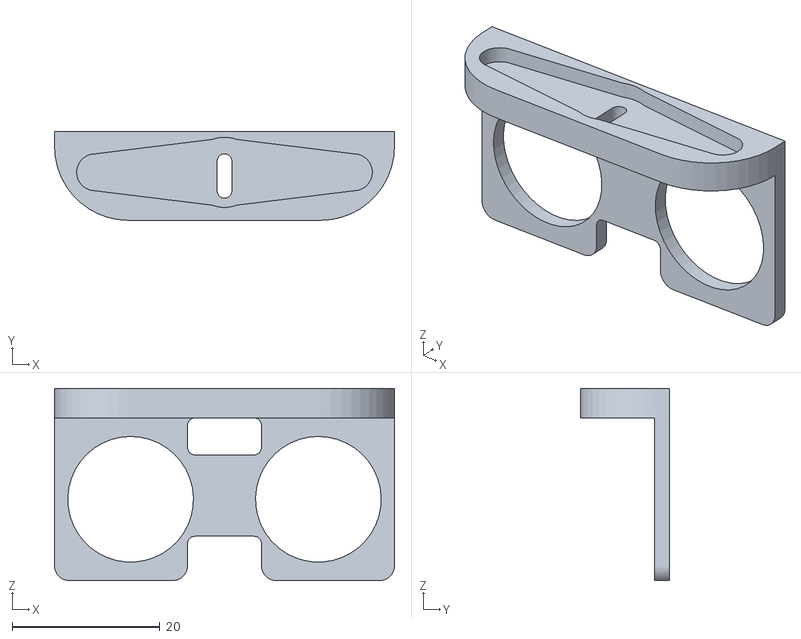
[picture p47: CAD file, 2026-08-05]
models/STL Files/finalultra_servo_holder.STL
46.0 x 12.0 x 26.0

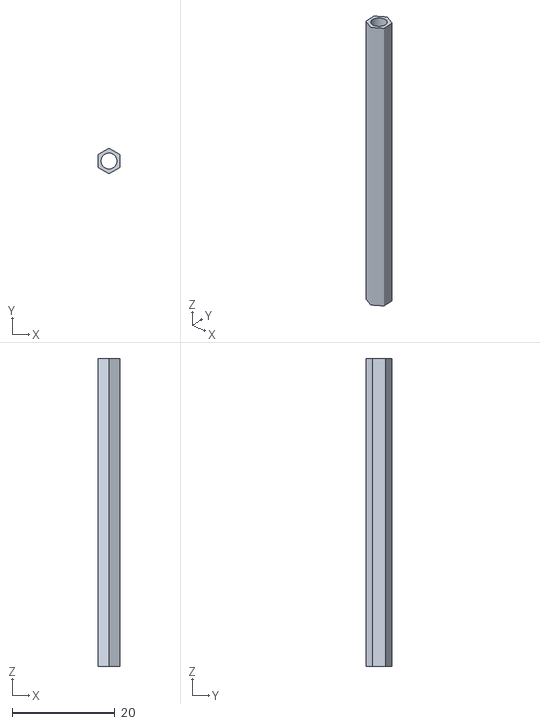
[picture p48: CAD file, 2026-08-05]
models/STL Files/Hexagonal Rod 6cm.STL
4.33 x 5.00 x 60.0

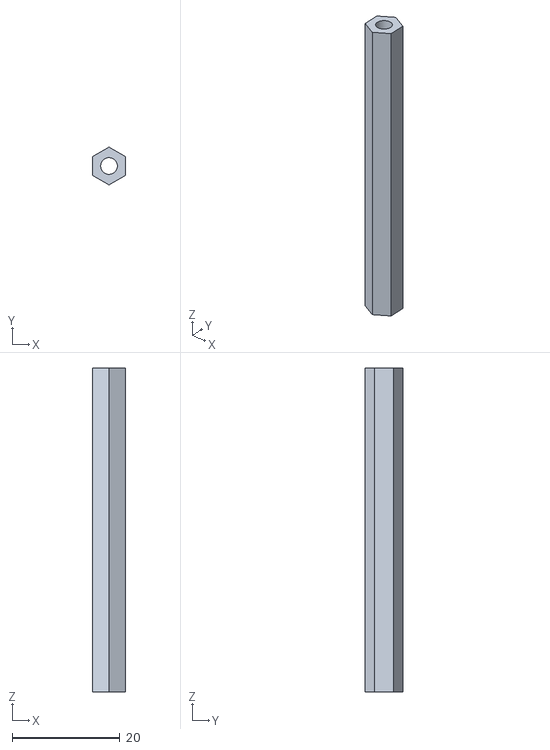
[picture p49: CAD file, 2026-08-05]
models/STL Files/Hexagonal Rod 6cm Thick.STL
6.06 x 7.00 x 60.0

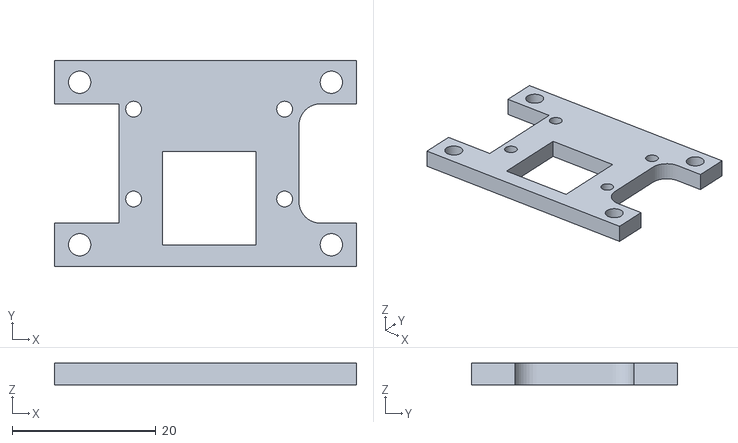
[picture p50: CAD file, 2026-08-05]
models/STL Files/finalnew_camera_holder2.STL
42.0 x 28.6 x 3.00

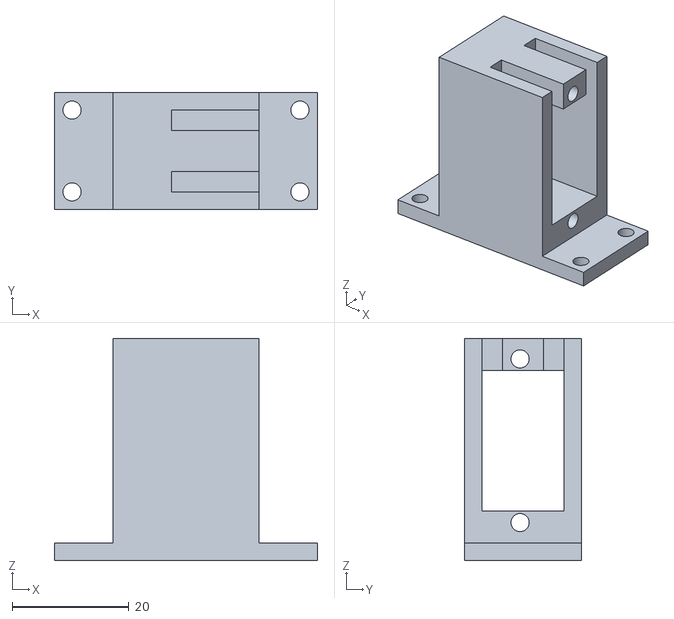
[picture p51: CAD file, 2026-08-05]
models/STL Files/finalCamera Servo Holder.STL
45.0 x 20.0 x 38.0

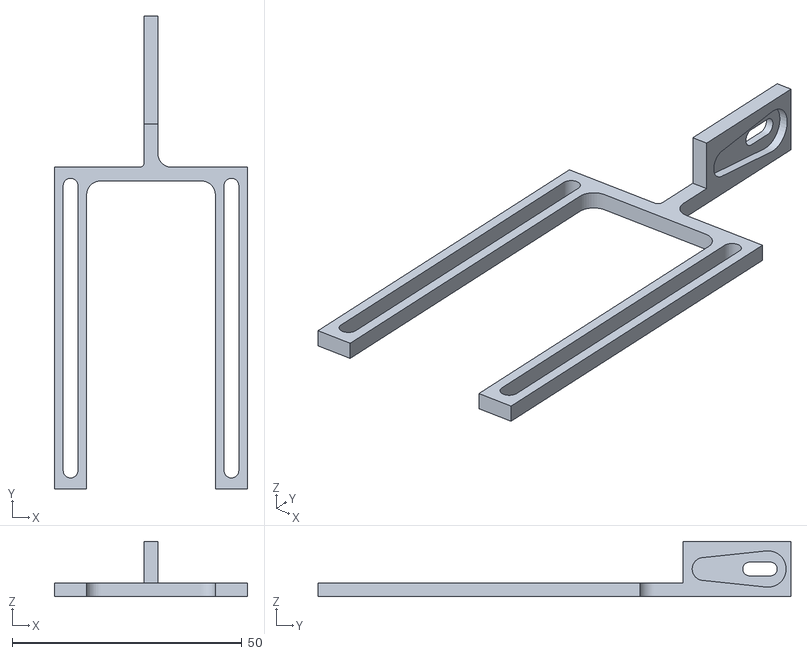
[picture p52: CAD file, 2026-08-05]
models/STL Files/finalnew_camera_holder1.STL
42.0 x 102.9 x 12.0

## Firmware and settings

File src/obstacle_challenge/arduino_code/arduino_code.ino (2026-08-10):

/*

  ╔══════════════════════════════════════════════════════════════════════════════════════════════════════════╗
  ║  ██████╗   ██████╗  ██████╗   ██████╗  ██████╗  ███████╗  ██████╗   █████╗  ███████╗ ██╗   ██╗ ███████╗  ║
  ║  ██╔══██╗ ██╔═══██╗ ██╔══██╗ ██╔═══██╗ ██╔══██╗ ██╔════╝ ██╔════╝  ██╔══██╗ ██╔════╝ ██║   ██║ ██╔════╝  ║
  ║  ██████╔╝ ██║   ██║ ██████╔╝ ██║   ██║ ██████╔╝ █████╗   ██║  ███╗ ███████║ ███████╗ ██║   ██║ ███████╗  ║
  ║  ██╔══██╗ ██║   ██║ ██╔══██╗ ██║   ██║ ██╔═══╝  ██╔══╝   ██║   ██║ ██╔══██║ ╚════██║ ██║   ██║ ╚════██║  ║
  ║  ██║  ██║ ╚██████╔╝ ██████╔╝ ╚██████╔╝ ██║      ███████╗ ╚██████╔╝ ██║  ██║ ███████║ ╚██████╔╝ ███████║  ║
  ║  ╚═╝  ╚═╝  ╚═════╝  ╚═════╝   ╚═════╝  ╚═╝      ╚══════╝  ╚═════╝  ╚═╝  ╚═╝ ╚══════╝  ╚═════╝  ╚══════╝  ║
  ╚══════════════════════════════════════════════════════════════════════════════════════════════════════════╝
    Autonomous Robot Navigation System | Arduino Mega Controller
    ─────────────────────────────────────────────────────────────

    🎯 Multi-Sensor Fusion Navigation & Obstacle Avoidance
    🚀 Advanced PID Control with IMU Integration
    🧠 Intelligent Wall Following & Autonomous Turning
    ⚡ Real-time Ultrasonic Array Processing

    Hardware: Arduino Mega, MPU6050, 7x Ultrasonic Sensors, Servo Motors
    Copyright © 2026 RoboPegasus Team | Autonomous Robotics Division

*/

#include <Servo.h>
#include <NewPing.h>
#include "Wire.h"
#include <MPU6050_light.h>
#include <ArduinoQueue.h>

// ============================================================================
// HARDWARE PIN DEFINITIONS
// ============================================================================

// Ultrasonic Sensor Pin Assignments
#define FRONT_TRIG_PIN 25
#define FRONT_ECHO_PIN 24
#define RIGHT_SIDE_TRIG_PIN 53
#define RIGHT_SIDE_ECHO_PIN 52
#define RIGHT_BACK_TRIG_PIN 23
#define RIGHT_BACK_ECHO_PIN 22
#define LEFT_SIDE_TRIG_PIN 12
#define LEFT_SIDE_ECHO_PIN 13
#define LEFT_BACK_TRIG_PIN 51
#define LEFT_BACK_ECHO_PIN 50
#define BACK_RIGHT_TRIG_PIN 29
#define BACK_RIGHT_ECHO_PIN 28
#define BACK_LEFT_TRIG_PIN 49
#define BACK_LEFT_ECHO_PIN 48

// Motor Control Pins
#define RIGHT_MOTOR_PWM 10
#define LEFT_MOTOR_PWM 9

// ============================================================================
// GLOBAL CONSTANTS AND CONFIGURATION
// ============================================================================

// Sensor Configuration
const int ULTRASONIC_MAX_DISTANCE = 300;
const int SENSOR_FILTER_SIZE = 7;
const double SOUND_VELOCITY_CM_US = 0.0343;

// Navigation Parameters
const int STEERING_CENTER_POSITION = 93;
const int LEFT_CENTER_POSITION = 90;
const int RIGHT_CENTER_POSITION = 80;
const int MAX_STEERING_ANGLE = STEERING_CENTER_POSITION + 35;
const int MIN_STEERING_ANGLE = STEERING_CENTER_POSITION - 50;
const int RIGHT_TURN_ANGLE = 40;
const int LEFT_TURN_ANGLE = -55;

// Speed Control Settings
const int NAVIGATION_SPEED = 60;
const int TURNING_SPEED = 60;
const int SAFETY_SPEED = 35;
const int WALL_FOLLOWING_DISTANCE = 15;

// PID Control Parameters
const float MPU_PROPORTIONAL_GAIN = 1.2;
const float MPU_DERIVATIVE_GAIN = 1.0;
const float MAXIMUM_ANGLE_CORRECTION = 0.27;

// ============================================================================
// SENSOR ARRAY DEFINITIONS
// ============================================================================

// Sensor ID Enumeration
enum SensorID {
  FRONT_SENSOR = 0,
  RIGHT_SIDE_SENSOR = 1,
  RIGHT_BACK_SENSOR = 2,
  BACK_RIGHT_SENSOR = 3,
  BACK_LEFT_SIDE_SENSOR = 4,
  LEFT_BACK_SENSOR = 5,
  LEFT_SIDE_SENSOR = 6
};

// Pin Arrays for Sensor Initialization
int ultrasonic_echo_pins[7] = {
  FRONT_ECHO_PIN, RIGHT_SIDE_ECHO_PIN, RIGHT_BACK_ECHO_PIN,
  BACK_RIGHT_ECHO_PIN, BACK_LEFT_ECHO_PIN, LEFT_BACK_ECHO_PIN, LEFT_SIDE_ECHO_PIN
};

int ultrasonic_trigger_pins[7] = {
  FRONT_TRIG_PIN, RIGHT_SIDE_TRIG_PIN, RIGHT_BACK_TRIG_PIN,
  BACK_RIGHT_TRIG_PIN, BACK_LEFT_TRIG_PIN, LEFT_BACK_TRIG_PIN, LEFT_SIDE_TRIG_PIN
};

// ============================================================================
// HARDWARE OBJECTS AND GLOBAL VARIABLES
// ============================================================================

// Servo Motor Objects
Servo steering_servo;
Servo left_gripper_servo;
Servo right_gripper_servo;

// IMU Object
MPU6050 inertial_measurement_unit(Wire);

// Ultrasonic Sensor Array
NewPing ultrasonic_sensors[7] = {
  NewPing(ultrasonic_trigger_pins[0], ultrasonic_echo_pins[0], ULTRASONIC_MAX_DISTANCE),
  NewPing(ultrasonic_trigger_pins[1], ultrasonic_echo_pins[1], ULTRASONIC_MAX_DISTANCE),
  NewPing(ultrasonic_trigger_pins[2], ultrasonic_echo_pins[2], ULTRASONIC_MAX_DISTANCE),
  NewPing(ultrasonic_trigger_pins[3], ultrasonic_echo_pins[3], ULTRASONIC_MAX_DISTANCE),
  NewPing(ultrasonic_trigger_pins[4], ultrasonic_echo_pins[4], ULTRASONIC_MAX_DISTANCE),
  NewPing(ultrasonic_trigger_pins[5], ultrasonic_echo_pins[5], ULTRASONIC_MAX_DISTANCE),
  NewPing(ultrasonic_trigger_pins[6], ultrasonic_echo_pins[6], ULTRASONIC_MAX_DISTANCE)
};

// ============================================================================
// SENSOR FILTERING SYSTEM
// ============================================================================

// Moving Average Filter Queues
ArduinoQueue<double> front_sensor_filter;
ArduinoQueue<double> right_side_filter;
ArduinoQueue<double> right_back_filter;
ArduinoQueue<double> left_side_filter;
ArduinoQueue<double> left_back_filter;
ArduinoQueue<double> back_left_filter;
ArduinoQueue<double> back_right_filter;

// Filtered Sensor Readings
double filtered_front_distance = 0;
double filtered_right_side_distance = 0;
double filtered_right_back_distance = 0;
double filtered_left_side_distance = 0;
double filtered_left_back_distance = 0;
double filtered_back_left_distance = 0;
double filtered_back_right_distance = 0;

// ============================================================================
// NAVIGATION STATE VARIABLES
// ============================================================================

// Turn Execution Flags
bool right_turn_completed = false;
bool left_turn_completed = false;
int total_turn_count = 0;

// Orientation Control
int imu_reference_angle = 0;
double target_steering_angle = 0;
double orientation_error = 0;
double ultrasonic_wall_error = 0;

// ============================================================================
// PILLAR COLORS VARIABLES
// ============================================================================

char colors[8] = {'N', 'N', 'N', 'N', 'N', 'N', 'N', 'N'}; // array to store the pillars
int current_pillar = 0; // pointer for the current pillar
String data = "NN"; // variable to store current two pillars

// Timing Control
long system_delay_timer;

// ============================================================================
// SENSOR DATA ACQUISITION FUNCTIONS
// ============================================================================

/**
   Apply moving average filter to sensor readings for noise reduction
   @param current_reading: Latest sensor measurement
   @param filtered_mean: Reference to filtered value storage
   @param filter_queue: Moving average queue for this sensor
   @return: Filtered sensor value
*/
double apply_sensor_filter(double current_reading, double &filtered_mean, ArduinoQueue<double> &filter_queue) {
  if (filter_queue.isEmpty()) {
    // Initialize filter with current reading
    filtered_mean = current_reading;
    for (int i = 0; i < SENSOR_FILTER_SIZE; i++) {
      filter_queue.enqueue(current_reading);
    }
  } else {
    // Update moving average
    double oldest_value = filter_queue.dequeue();
    filtered_mean -= (oldest_value / SENSOR_FILTER_SIZE);
    filtered_mean += (current_reading / SENSOR_FILTER_SIZE);
    filter_queue.enqueue(current_reading);
  }
  return filtered_mean;
}

/**
   Get filtered distance measurement from front ultrasonic sensor
   @return: Filtered distance in centimeters
*/
double measure_front_distance() {
  double pulse_duration = ultrasonic_sensors[FRONT_SENSOR].ping();
  double raw_distance = (pulse_duration / 2) * SOUND_VELOCITY_CM_US;

  if (raw_distance == 0) raw_distance = ULTRASONIC_MAX_DISTANCE;

  return apply_sensor_filter(raw_distance, filtered_front_distance, front_sensor_filter);
}

/**
   Get filtered distance measurement from right side ultrasonic sensor
   @return: Filtered distance in centimeters
*/
double measure_right_side_distance() {
  double pulse_duration = ultrasonic_sensors[RIGHT_SIDE_SENSOR].ping();
  double raw_distance = (pulse_duration / 2) * SOUND_VELOCITY_CM_US;

  if (raw_distance == 0) raw_distance = ULTRASONIC_MAX_DISTANCE;

  return apply_sensor_filter(raw_distance, filtered_right_side_distance, right_side_filter);
}

/**
   Get filtered distance measurement from left side ultrasonic sensor
   @return: Filtered distance in centimeters
*/
double measure_left_side_distance() {
  double pulse_duration = ultrasonic_sensors[LEFT_SIDE_SENSOR].ping();
  double raw_distance = (pulse_duration / 2) * SOUND_VELOCITY_CM_US;

  if (raw_distance == 0) raw_distance = ULTRASONIC_MAX_DISTANCE;

  return apply_sensor_filter(raw_distance, filtered_left_side_distance, left_side_filter);
}

/**
   Get filtered distance measurement from back left ultrasonic sensor
   @return: Filtered distance in centimeters
*/
double measure_back_left_distance() {
  double pulse_duration = ultrasonic_sensors[BACK_LEFT_SIDE_SENSOR].ping();
  double raw_distance = (pulse_duration / 2) * SOUND_VELOCITY_CM_US;

  if (raw_distance == 0) raw_distance = ULTRASONIC_MAX_DISTANCE;

  return apply_sensor_filter(raw_distance, filtered_back_left_distance, back_left_filter);
}

/**
   Get filtered distance measurement from back right ultrasonic sensor
   @return: Filtered distance in centimeters
*/
double measure_back_right_distance() {
  double pulse_duration = ultrasonic_sensors[BACK_RIGHT_SENSOR].ping();
  double raw_distance = (pulse_duration / 2) * SOUND_VELOCITY_CM_US;

  if (raw_distance == 0) raw_distance = ULTRASONIC_MAX_DISTANCE;

  return apply_sensor_filter(raw_distance, filtered_back_right_distance, back_right_filter);
}

/**
   Get unfiltered distance measurement for quick obstacle detection
   @param sensor_id: ID of the sensor to read
   @return: Raw distance measurement in centimeters
*/
double get_instant_distance(int sensor_id) {
  double pulse_duration = ultrasonic_sensors[sensor_id].ping();
  double distance = (pulse_duration / 2) * SOUND_VELOCITY_CM_US;

  if (distance == 0) distance = ULTRASONIC_MAX_DISTANCE;

  return distance;
}

/**
   Reset all sensor filters to clear accumulated data
*/
void reset_sensor_filters() {
  for (int i = 0; i < SENSOR_FILTER_SIZE; i++) {
    if (!front_sensor_filter.isEmpty()) front_sensor_filter.dequeue();
    if (!right_side_filter.isEmpty()) right_side_filter.dequeue();
    if (!right_back_filter.isEmpty()) right_back_filter.dequeue();
    if (!left_side_filter.isEmpty()) left_side_filter.dequeue();
    if (!left_back_filter.isEmpty()) left_back_filter.dequeue();
    if (!back_left_filter.isEmpty()) back_left_filter.dequeue();
    if (!back_right_filter.isEmpty()) back_right_filter.dequeue();
  }
}

// ============================================================================
// MOTOR CONTROL FUNCTIONS
// ============================================================================

/**
   Drive robot forward at specified speed
   @param speed_percentage: Motor speed as percentage (0-100)
*/
void drive_forward(int speed_percentage) {
  int pwm_value = speed_percentage * 254 / 100;
  analogWrite(LEFT_MOTOR_PWM, 0);
  analogWrite(RIGHT_MOTOR_PWM, pwm_value);
}

/**
   Drive robot backward at specified speed
   @param speed_percentage: Motor speed as percentage (0-100)
*/
void drive_backward(int speed_percentage) {
  int pwm_value = speed_percentage * 254 / 100;
  analogWrite(RIGHT_MOTOR_PWM, 0);
  analogWrite(LEFT_MOTOR_PWM, pwm_value);
}

/**
   Stop all motor movement
*/
void stop_motors() {
  analogWrite(RIGHT_MOTOR_PWM, 0);
  analogWrite(LEFT_MOTOR_PWM, 0);
}

// ============================================================================
// TIMING AND DELAY FUNCTIONS
// ============================================================================

/**
   Non-blocking delay that maintains IMU updates
   @param delay_milliseconds: Duration to delay in milliseconds
*/
void maintain_imu_during_delay(int delay_milliseconds) {
  system_delay_timer = millis();
  while (millis() - system_delay_timer < delay_milliseconds) {
    inertial_measurement_unit.update();
  }
}

// ============================================================================
// PID CONTROL FUNCTIONS
// ============================================================================

/**
   PID control for maintaining orientation during backward movement
*/
void backward_orientation_control() {
  orientation_error = inertial_measurement_unit.getAngleZ() - imu_reference_angle;
  target_steering_angle = STEERING_CENTER_POSITION + (MPU_PROPORTIONAL_GAIN * orientation_error);

  // Apply steering limits
  if (target_steering_angle > MAX_STEERING_ANGLE) target_steering_angle = MAX_STEERING_ANGLE;
  if (target_steering_angle < MIN_STEERING_ANGLE) target_steering_angle = MIN_STEERING_ANGLE;

  steering_servo.write(target_steering_angle);
}

/**
   PID control for maintaining orientation during forward movement
*/
void forward_orientation_control() {
  orientation_error = inertial_measurement_unit.getAngleZ() - imu_reference_angle;
  target_steering_angle = STEERING_CENTER_POSITION - (MPU_PROPORTIONAL_GAIN * orientation_error);

  // Apply steering limits
  if (target_steering_angle > MAX_STEERING_ANGLE) target_steering_angle = MAX_STEERING_ANGLE;
  if (target_steering_angle < MIN_STEERING_ANGLE) target_steering_angle = MIN_STEERING_ANGLE;

  steering_servo.write(target_steering_angle);
}

/**
   PID control for maintaining orientations of servos that holds ultrasonic sensors during movement
*/

void servo_ultra_pid() {
  float error = inertial_measurement_unit.getAngleZ() - imu_reference_angle;
  delay(10);
  if (error > 80) {
    left_gripper_servo.write(LEFT_CENTER_POSITION - 80);
    right_gripper_servo.write(RIGHT_CENTER_POSITION - 80);
  }
  else if (error < -80) {
    left_gripper_servo.write(LEFT_CENTER_POSITION + 80);
    right_gripper_servo.write(RIGHT_CENTER_POSITION + 80);
  }
  else {
    left_gripper_servo.write(LEFT_CENTER_POSITION - error);
    right_gripper_servo.write(RIGHT_CENTER_POSITION - error);
  }
}
/**
   Wall following control for left side obstacles
   @param wall_distance: Current distance to left wall
*/
void maintain_left_wall_distance(double wall_distance) {
  if (wall_distance < WALL_FOLLOWING_DISTANCE) {
    ultrasonic_wall_error = WALL_FOLLOWING_DISTANCE - wall_distance;
    steering_servo.write(STEERING_CENTER_POSITION + 1.2 * ultrasonic_wall_error);
    maintain_imu_during_delay(10);
  }
}

/**
   Wall following control for right side obstacles
   @param wall_distance: Current distance to right wall
*/
void maintain_right_wall_distance(double wall_distance) {
  if (wall_distance < WALL_FOLLOWING_DISTANCE) {
    ultrasonic_wall_error = WALL_FOLLOWING_DISTANCE - wall_distance;
    steering_servo.write(STEERING_CENTER_POSITION - 1.2 * ultrasonic_wall_error);
    maintain_imu_during_delay(10);
  }
}

// ============================================================================
// NAVIGATION MANEUVER FUNCTIONS
// ============================================================================

/**
   Execute 90-degree right turn maneuver
*/
void execute_right_turn() {
  // Prevent multiple consecutive turns
  if (right_turn_completed && total_turn_count != 0) return;

  maintain_imu_during_delay(30);

  // Handle front obstacle during turn initiation
  if (get_instant_distance(FRONT_SENSOR) < 35) {
    stop_motors();
    maintain_imu_during_delay(30);

    // Back away from obstacle
    while (get_instant_distance(FRONT_SENSOR) < 40) {
      drive_backward(SAFETY_SPEED);
      backward_orientation_control();
      maintain_imu_during_delay(30);
    }

    stop_motors();
    maintain_imu_during_delay(20);
    drive_forward(SAFETY_SPEED);
    maintain_imu_during_delay(250);
  }

  // Execute turning sequence
  steering_servo.write(STEERING_CENTER_POSITION + RIGHT_TURN_ANGLE);
  drive_forward(TURNING_SPEED);
  inertial_measurement_unit.update();

  // Turn until 70-degree rotation achieved
  while (inertial_measurement_unit.getAngleZ() < imu_reference_angle + 70) {
    inertial_measurement_unit.update();
  }

  // Update reference angle and complete turn
  imu_reference_angle += 90;
  stop_motors();
  maintain_imu_during_delay(50);
  steering_servo.write(STEERING_CENTER_POSITION);
  maintain_imu_during_delay(50);

  // Resume navigation
  drive_forward(NAVIGATION_SPEED);
  inertial_measurement_unit.update();
  forward_orientation_control();
  reset_sensor_filters();

  right_turn_completed = true;
  total_turn_count++;
  maintain_imu_during_delay(30);

  // Navigate until clear of turn area
  while (measure_back_left_distance() < 110 && measure_back_right_distance() < 110) {
    maintain_imu_during_delay(30);
    maintain_right_wall_distance(measure_right_side_distance());
    maintain_left_wall_distance(measure_left_side_distance());
    maintain_imu_during_delay(30);

    if (measure_right_side_distance() > WALL_FOLLOWING_DISTANCE &&
        measure_left_side_distance() > WALL_FOLLOWING_DISTANCE) {
      forward_orientation_control();
    }
  }
}

/**
   Execute 90-degree left turn maneuver
*/
void execute_left_turn() {
  // Prevent multiple consecutive turns
  if (left_turn_completed && total_turn_count != 0) return;

  maintain_imu_during_delay(30);

  // Handle front obstacle during turn initiation
  if (get_instant_distance(FRONT_SENSOR) < 35) {
    stop_motors();
    maintain_imu_during_delay(30);

    // Back away from obstacle
    while (get_instant_distance(FRONT_SENSOR) < 40) {
      drive_backward(SAFETY_SPEED);
      backward_orientation_control();
      maintain_imu_during_delay(30);
    }

    stop_motors();
    maintain_imu_during_delay(20);
    drive_forward(SAFETY_SPEED);
    maintain_imu_during_delay(250);
  }

  // Execute turning sequence
  steering_servo.write(STEERING_CENTER_POSITION + LEFT_TURN_ANGLE);
  drive_forward(TURNING_SPEED);
  inertial_measurement_unit.update();

  // Turn until 70-degree rotation achieved
  while (inertial_measurement_unit.getAngleZ() > imu_reference_angle - 70) {
    inertial_measurement_unit.update();
  }

  // Update reference angle and complete turn
  imu_reference_angle -= 90;
  stop_motors();
  maintain_imu_during_delay(50);
  steering_servo.write(STEERING_CENTER_POSITION);
  maintain_imu_during_delay(50);

  // Resume navigation
  drive_forward(NAVIGATION_SPEED);
  inertial_measurement_unit.update();
  forward_orientation_control();
  reset_sensor_filters();

  left_turn_completed = true;
  total_turn_count++;
  maintain_imu_during_delay(30);

  // Navigate until clear of turn area
  while (measure_back_left_distance() < 110 && measure_back_right_distance() < 110) {
    maintain_imu_during_delay(30);
    maintain_right_wall_distance(measure_right_side_distance());
    maintain_left_wall_distance(measure_left_side_distance());
    maintain_imu_during_delay(30);

    if (measure_right_side_distance() > WALL_FOLLOWING_DISTANCE &&
        measure_left_side_distance() > WALL_FOLLOWING_DISTANCE) {
      forward_orientation_control();
    }
  }
}



// ============================================================================
// READING PILLARS' COLORS FUNCTION
// ============================================================================

void READ_PILLAR_COLOR() {
  stop_motors(); // stop the motor so the camera can take a clear frame
  delay(3000);
  if (Serial.available() > 0) {
    data = Serial.readStringUntil('#'); // take the data recived from raspberry pi through Serial connection
    Serial.println(data);
    // Store the data in the pillar colors array
    colors[current_pillar] = data[0];
    colors[current_pillar + 1] = data[1];
  }

}
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
void loop() {
  // Start the round and determine the driving direction
  if (get_instant_distance(RIGHT_SIDE_SENSOR) < get_instant_distance(LEFT_SIDE_SENSOR))
  {
    Serial.println("CCW");
    left_turn_completed = true;
    startup_ccw();
  }
  else
  {
    Serial.println("CW");
    right_turn_completed = true ;
    startup_cw();
  }


  for (int sec_num = 0; sec_num < 10; sec_num++) // pass all sections except the starting section and the ending section
  {
    if (sec_num < 4) // if it is the first lap, take color data from camera and store them in the array
    {
      READ_PILLAR_COLOR();
    }
    // pass the two pillars in the section depending on their colors if there is one pillar, it will be duplicated
    if (colors[current_pillar] == 'R') pass_red_pillar();
    else if (colors[current_pillar] == 'G') pass_green_pillar();
    current_pillar = (current_pillar + 1) % 8;

    if (colors[current_pillar] == 'R') pass_red_pillar();
    else if (colors[current_pillar] == 'G') pass_green_pillar();
    current_pillar = (current_pillar + 1) % 8;

    // Turn to the next section
    if (right_turn_completed) execute_right_turn();
    else if (left_turn_completed) execute_left_turn();

  }

  // park the robot

  if (right_turn_completed) PARKING_CW();
  else if (left_turn_completed) PARKING_CCW();

}

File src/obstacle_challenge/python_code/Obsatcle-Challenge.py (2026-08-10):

"""

╔══════════════════════════════════════════════════════════════════════════════════════════════════════════╗
║  ██████╗   ██████╗  ██████╗   ██████╗  ██████╗  ███████╗  ██████╗   █████╗  ███████╗ ██╗   ██╗ ███████╗  ║
║  ██╔══██╗ ██╔═══██╗ ██╔══██╗ ██╔═══██╗ ██╔══██╗ ██╔════╝ ██╔════╝  ██╔══██╗ ██╔════╝ ██║   ██║ ██╔════╝  ║
║  ██████╔╝ ██║   ██║ ██████╔╝ ██║   ██║ ██████╔╝ █████╗   ██║  ███╗ ███████║ ███████╗ ██║   ██║ ███████╗  ║
║  ██╔══██╗ ██║   ██║ ██╔══██╗ ██║   ██║ ██╔═══╝  ██╔══╝   ██║   ██║ ██╔══██║ ╚════██║ ██║   ██║ ╚════██║  ║
║  ██║  ██║ ╚██████╔╝ ██████╔╝ ╚██████╔╝ ██║      ███████╗ ╚██████╔╝ ██║  ██║ ███████║ ╚██████╔╝ ███████║  ║
║  ╚═╝  ╚═╝  ╚═════╝  ╚═════╝   ╚═════╝  ╚═╝      ╚══════╝  ╚═════╝  ╚═╝  ╚═╝ ╚══════╝  ╚═════╝  ╚══════╝  ║
╚══════════════════════════════════════════════════════════════════════════════════════════════════════════╝                                                                                              
   Autonomous Robot Vision System | Pillar Detection & Navigation
   ──────────────────────────────────────────────────────────────
    
    🎯 Advanced Computer Vision for Obstacle Course Navigation
    🚀 Real-time HSV Color Classification & Morphological Processing
    🧠 Intelligent Pillar Configuration Analysis
    ⚡ High-Performance Arduino Communication Interface
    
    Copyright © 2026 RoboPegasus Team | Autonomous Robotics Division

"""    
import serial
import numpy as np
import time
from picamera2 import Picamera2
import cv2 as cv2

# Minimum area thresholds for pillar detection
RED_PILLAR_MIN_AREA = 1700
GREEN_PILLAR_MIN_AREA = 2100

# Global variables for navigation state
navigation_mode = None
initial_pillar_detected = False

def initialize_camera_system():
    """
    Configure and initialize the camera with optimized settings for pillar detection.
    Returns configured camera instance.
    """
    cam = Picamera2()
    camera_config = cam.create_preview_configuration()
    camera_config['main']['format'] = 'RGB888'
    cam.configure(camera_config)
    cam.start()
    cam.set_controls({"AfMode": 1, "LensPosition": 425, "AwbEnable": False})
    return cam

def establish_arduino_connection(port_name='/dev/ttyACM0', baud_rate=115200):
    """
    Establish serial communication with Arduino controller.
    Sends initialization signal and waits for confirmation.
    """
    arduino_link = serial.Serial(port_name, baud_rate, timeout=1)
    arduino_link.flush()
    time.sleep(3.5)
    arduino_link.write("S#".encode('ascii'))
    print("Setup response:", arduino_link.readline().decode().strip())
    return arduino_link

def generate_corner_exclusion_mask(frame_dimensions, exclusion_size=(50, 50)):
    """
    Create a mask to exclude corner regions from pillar detection.
    This prevents false detections from corner artifacts.
    """
    height, width, _ = frame_dimensions
    mask = np.ones((height, width), dtype=np.uint8) * 255
    
    # Exclude top-left corner
    mask[0:exclusion_size[1], 0:exclusion_size[0]] = 0
    
    # Exclude top-right corner  
    x_right = width - exclusion_size[0]
    mask[0:exclusion_size[1], x_right:width] = 0
    
    return mask

def transmit_pillar_information(arduino_connection, pillar_data):
    """
    Send pillar detection results to Arduino controller.
    Appends termination character and handles response.
    """
    message = pillar_data + '#'
    arduino_connection.write(message.encode('ascii'))
    time.sleep(0.1)
    print(arduino_connection.readline())

def extract_pillar_features(color_mask, area_threshold, pillar_type):
    """
    Extract pillar features from color-filtered mask.
    Returns list of detected pillars with their properties.
    """
    # Apply morphological operations to reduce noise
    morphology_kernel = np.ones((5, 5), np.uint8)
    filtered_mask = cv2.morphologyEx(color_mask, cv2.MORPH_OPEN, morphology_kernel)
    filtered_mask = cv2.morphologyEx(filtered_mask, cv2.MORPH_CLOSE, morphology_kernel)

    # Find contours in the processed mask
    contour_list, _ = cv2.findContours(filtered_mask, cv2.RETR_EXTERNAL, cv2.CHAIN_APPROX_SIMPLE)
    
    pillar_objects = []
    for contour in contour_list:
        contour_area = cv2.contourArea(contour)
        
        if contour_area > area_threshold:
            # Calculate centroid coordinates
            moments = cv2.moments(contour)         
            center_x = int(moments["m10"] / moments["m00"])
            
            pillar_objects.append({
                'color': pillar_type,
                'cx': center_x,
                'area': contour_area
            })
    
    return pillar_objects

def process_color_detection(frame_data, red_range_1, red_range_2, green_range):
    """
    Apply color filtering to detect red and green pillars in the frame.
    Returns detected pillar objects and visualization masks.
    """
    hsv_converted = cv2.cvtColor(frame_data, cv2.COLOR_RGB2HSV)
    
    # Create color masks for red and green pillars
    red_mask_lower = cv2.inRange(hsv_converted, *red_range_1)
    red_mask_upper = cv2.inRange(hsv_converted, *red_range_2)
    red_combined_mask = cv2.bitwise_xor(red_mask_lower, red_mask_upper)
    green_mask = cv2.inRange(hsv_converted, *green_range)

    # Extract pillar features from masks
    red_pillars = extract_pillar_features(red_combined_mask, min_area=200, pillar_type='R')
    green_pillars = extract_pillar_features(green_mask, min_area=300, pillar_type='G')
    
    return red_pillars, green_pillars, red_combined_mask, green_mask
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

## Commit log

2026-08-05 Add 3D-printed part files (1/2)
    [finalCamera Servo Holder.STL, finalMotor_Holder.STL, finaldc_to_diff.STL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]
2026-08-05 Add 3D-printed part files (2/2)
    [Hexagonal Rod 6cm Thick.STL, Hexagonal Rod 6cm.STL, finalultra_back.STL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]
2026-08-05 Add laser-cut part files
    [Floor_Plexi.DXF, Roof_Plexi.DXF, Second_Plexi.DXF]
2026-08-05 README: Mobility and Mechanical Design -- Chassis
2026-08-05 README: Mobility -- Drivetrain
2026-08-05 README: Mobility -- Steering
2026-08-05 README: Power and Sensor Architecture intro
2026-08-05 README: Power -- Power source and distribution
2026-08-05 README: Power -- Processing
2026-08-05 README: Power -- Sensor array
2026-08-05 README: Power -- Sensor placement field-geometry reasoning
2026-08-05 README: Power -- What judges look for
2026-08-05 README: Power -- Wiring diagram (+ reused diagram asset)
2026-08-05 README: Power -- Calibration
2026-08-05 README: Software -- State machine and control flow
2026-08-06 README: Vehicle regulations -- Drivetrain and wheels
2026-08-06 README: Vehicle regulations -- Controllers and materials
2026-08-06 README: strip citations -- Power and Sensor Architecture
2026-08-06 README: strip citations -- Vehicle Material & Regulations Compliance
2026-08-06 Add Ackermann steering diagrams (reused, source: team-2025)
2026-08-06 Add chassis component photos (reused, source: team-2025)
2026-08-06 Add motor/servo component photos (reused, source: team-2025)
2026-08-06 Add power management system photos (reused, source: team-2025)
2026-08-06 Add battery/driver/processor photos (reused, source: team-2025)
2026-08-06 Add unchanged sensor photos (reused, source: team-2025)
2026-08-06 Add real 2026 sensor photos (URM09, BNO086 -- from the team, not reused)
2026-08-06 Add pillar-color detection camera/mask images (reused, source: team-2025)
2026-08-06 README: add Power and Sensor Architecture photos (incl. real URM09/BNO086)
2026-08-06 README: add all Obstacle Challenge step images and SG90/IR sensor photos
2026-08-06 README: add remaining Open Challenge and single-pillar camera photos
2026-08-08 README: remove internal process/audit-trail commentary
    The verification pipeline that built this documentation left ~24
    process notes in the published text -- "adapted from last year's team
    repository (source: team-2025), confirmed by the team", "not carried
    over", "not evidence about this year's rules", etc. That was an
    internal grounding mechanism during drafting, never meant to be
    published. Removed every instance (both the standalone italic notes
    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
2026-08-08 README: remove remaining self-justifying/meta-commentary sentences
    An independent audit pass (separate from the previous cleanup) caught
    5 more instances the first pass missed: sentences that argue their
    own legitimacy or narrate the document's own scope/reasoning rather
    than stating facts -- "we already have real evidence", "this year's
    actual sensors" (redundant with the model already stated above), "not
    a generic list", "not a hypothetical one", "not an attempt to
    disguise... the kind the rules anticipate, not the kind rule 3.7
    prohibits", and an aside about not needing to state whether the coach
    coaches other teams. All underlying facts kept; only the
    self-defending framing removed.
2026-08-10 README: add consolidated bill-of-materials table
2026-08-10 Regenerate Engineering Journal PDF with table of contents, BOM table, and markdown-conversion fixes
2026-08-10 README: disclose camera-calibration process, add build/upload instructions, fix stale cross-reference
2026-08-10 Regenerate Engineering Journal PDF: drop illegible flowchart screenshots, point readers to GitHub README instead
2026-08-10 src: add Open Challenge Arduino control code
2026-08-10 src: add Obstacle Challenge Arduino control code
2026-08-10 README: tighten image layout in Drivetrain and Steering subsections
2026-08-10 README: replace state diagram with flowchart to fix mermaid rendering (self-loops are a known mermaid bug)
2026-08-10 Regenerate Engineering Journal PDF after flowchart diagram fix
2026-08-10 README: remove infrared sensor (no longer used), update battery quantity to 2
2026-08-10 Regenerate Engineering Journal PDF: infrared sensor removed, battery qty updated
2026-08-10 README: add prices to bill-of-materials table
2026-08-10 Regenerate Engineering Journal PDF with BOM pricing
2026-08-10 README: convert chassis photo galleries to captioned tables
2026-08-10 README: convert drivetrain photo galleries to captioned tables
2026-08-10 README: convert steering photo gallery to captioned table
2026-08-10 README: convert power source photo gallery to captioned tables
2026-08-10 README: convert sensor array photo gallery to captioned tables
2026-08-10 README: convert pillar-pair camera photo gallery to captioned table
2026-08-10 README: convert single-pillar camera photo gallery to captioned table
2026-08-10 README: convert red pillar case photo gallery to captioned table
2026-08-10 README: convert green pillar case photo gallery to captioned table
2026-08-10 README: reduce red pillar case table to 2 columns for legibility
2026-08-10 README: reduce green pillar case table to 2 columns for legibility
2026-08-10 Regenerate Engineering Journal PDF with larger step-diagram images for print legibility
2026-08-12 Add team photos, fix chassis dimensions, and clean up Engineering Journal PDF
    - Add funny_photo.jpg and official_photo.jpg to t-photos
    - Correct chassis dimensions (24x15x29cm, 1.45kg) and drop the outdated
    rear-panel center-of-mass sentence in README and Engineering Journal
    - Add the wiring diagram image to section 3.6
    - Note that algorithm flow diagrams are better viewed on GitHub than in
    the PDF
    - Remove all GIF-based images (startup sequences, pillar cases, Open
    Challenge demo) from the PDF since PDFs don't render GIFs
2026-08-12 README: reword drivetrain testing sentence
2026-08-12 README: reword power section intro
2026-08-12 README: reword sensor array intro
2026-08-12 README: reword Arduino/Pi communication sentence
2026-08-12 README: reword gear-ratio photos caption
2026-08-12 README: reword bill of materials intro
2026-08-12 README: reword sensor placement reasoning intro
2026-08-12 README: reword controllers/materials sentence
